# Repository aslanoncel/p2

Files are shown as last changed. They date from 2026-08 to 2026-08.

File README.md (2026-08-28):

# Marenova K1 — Vinç Makara Alt-Montajı (Parametrik CAD)

Yelkenli hidro-jeneratör masa prototipinin vinç makara alt-montajı için FDM 3D
baskıya uygun, tamamen parametrik CadQuery (Python) modeli.

## İçerik

```
cad/
  marenova_k1_winch.py   # tek parametrik kaynak dosya (tüm parçalar)
  stl/
    test_coupon.stl      # ~10 dk kalibrasyon kuponu — ÖNCE BUNU BASIN
    spool.stl            # makara
    motor_bracket.stl    # NEMA 17 motor braketi
    slipring_clamp.stl   # Ø12 kapsül slip ring tutucu
    line_guide.stl       # misina kılavuzu + limit switch bayrağı
```

## Kullanım

```bash
pip install cadquery
python3 cad/marenova_k1_winch.py
```

Betik `cad/stl/` altına her parça için ayrı STL yazar ve her parça için
hacim / tahmini kütle (PLA, %100 katı) / bounding box raporlar. Tüm kritik
ölçüler dosyanın başında parametre olarak tanımlıdır.

## Kalibrasyon iş akışı (önemli)

H7/g6 gibi işleme toleransları FDM'de geçersizdir; yerine baskı boşlukları
kullanılır:

| Parametre | Varsayılan | Anlam |
|---|---:|---|
| `CLEAR_SLIDE` | +0.20 mm | Mil geçmesi (makara ↔ NEMA17 D-şaft) |
| `CLEAR_PRESS` | +0.10 mm | Sıkı geçme (slip ring ↔ kelepçe) |
| `CLEAR_FREE`  | +0.35 mm | Serbest dönme (yedek) |

1. **Önce `test_coupon.stl` basın** (~10 dk): 5 mm D-şaft deliği + Ø12
   kelepçe deliği + Ø2 misina deliği içerir.
2. NEMA17 miline ve slip ring kapsülüne deneyin. Uymazsa `CLEAR_*`
   değerlerini 0.05 mm adımlarla değiştirip kuponu yeniden basın.
3. Boşluklar doğrulanınca asıl parçaları basın.

## Baskı yönelimleri (desteksiz)

| Parça | Yönelim |
|---|---|
| `spool` | Geldiği gibi: motor karşısı flanş tabana. Üst flanş 45° koni ile bağlanır, setskur göbeği en üstte, somun yuvası yukarı açık → köprü/destek yok. Kullanımda ters çevrilir (göbek motora bakar). |
| `motor_bracket`  | Geldiği gibi: taban tablaya. Ø23 delik gözyaşı tepeli, destekler 45°. |
| `slipring_clamp` | Yan yatık (geniş yüzeyi tablaya). Ø12 delik baskıda dikey → temiz daire. |
| `line_guide` | Yan yatık (geniş yüzeyi tablaya). |
| `test_coupon` | Geldiği gibi, düz. |

- Minimum et kalınlığı 2.4 mm (3 çeper × 0.8 mm nozul) gözetilmiştir.
- Somun cepleri baskı yönünde köprü gerektirmez (yukarı açık yuva veya
  kendini taşıyan çatılı cep).
- Makara hacmi ~219 cm³'tür; %15–20 infill ile basın (katı basmayın).

## Montaj notları

- Ortak eksen yüksekliği `AXIS_H = 45 mm` (MDF taban üstünden): motor mili,
  makara, slip ring ve kılavuz gözü aynı hizadadır.
- Makara: M3 başsız setskur (8 mm) göbekteki yukarıdan takılan M3 somuna
  vidalanır ve milin düz (D) yüzeyine basar.
- Slip ring: gövde kelepçeyle sabitlenir (dönmez); kapsülün kendi mili
  makarayla birlikte döner. Kelepçe M3×16 civata + somunla sıkılır.
- Kılavuz: esneme boynu sayesinde misina gerginliğiyle hafifçe salınır;
  salınım sonunda üstteki bayrak limit switch koluna basar.
- Tüm ayaklar 400×300 mm MDF tabana M4 vidayla bağlanır.

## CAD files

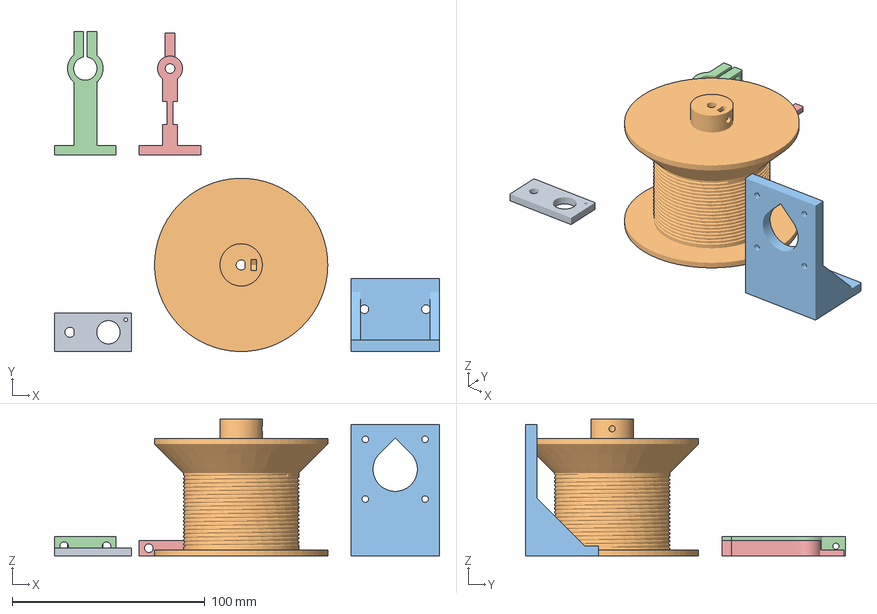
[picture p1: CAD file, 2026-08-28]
cad/marenova_k1_plate.3mf
199.9 x 166.2 x 71.0 mm
test_coupon
spool
motor_bracket
slipring_clamp
line_guide

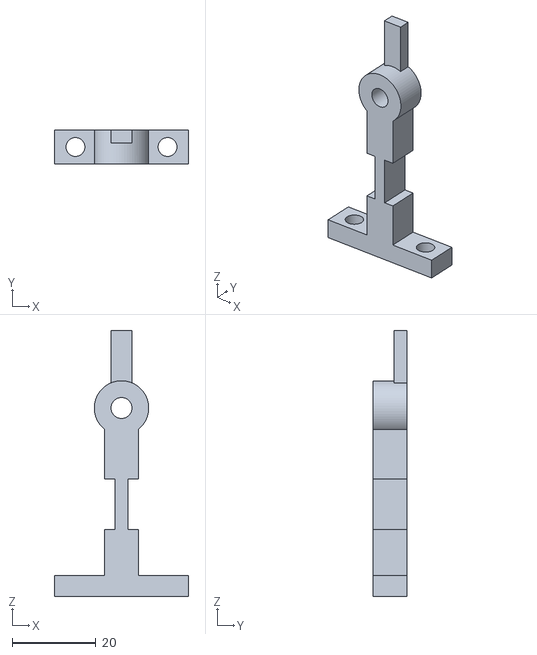
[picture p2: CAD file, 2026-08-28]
cad/stl/line_guide.stl
32.0 x 8.00 x 63.5

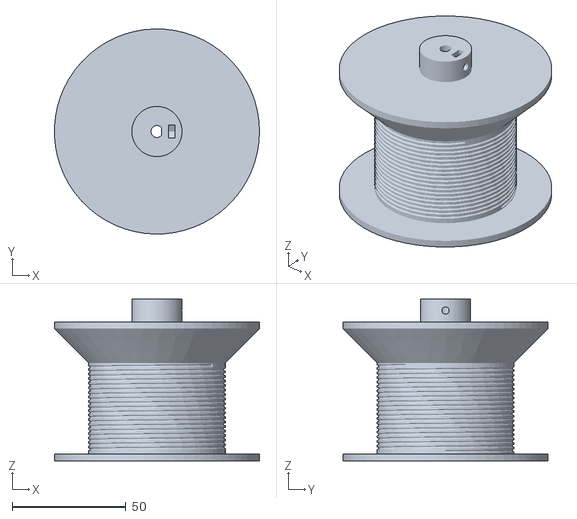
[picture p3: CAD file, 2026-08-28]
cad/stl/spool.stl
89.9 x 90.0 x 71.0

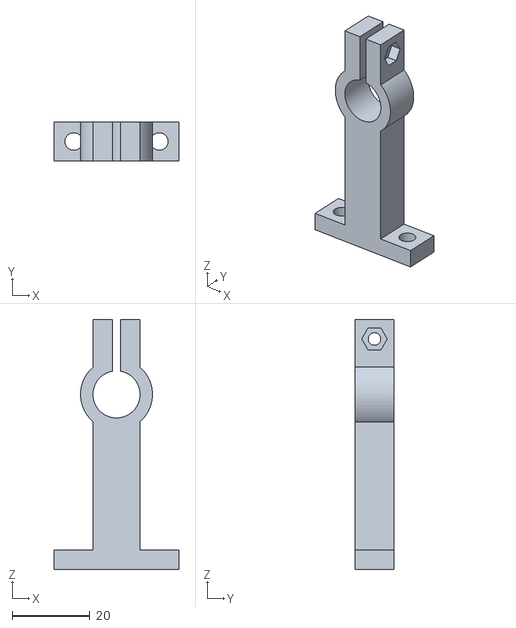
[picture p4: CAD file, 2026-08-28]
cad/stl/slipring_clamp.stl
32.0 x 10.0 x 64.2

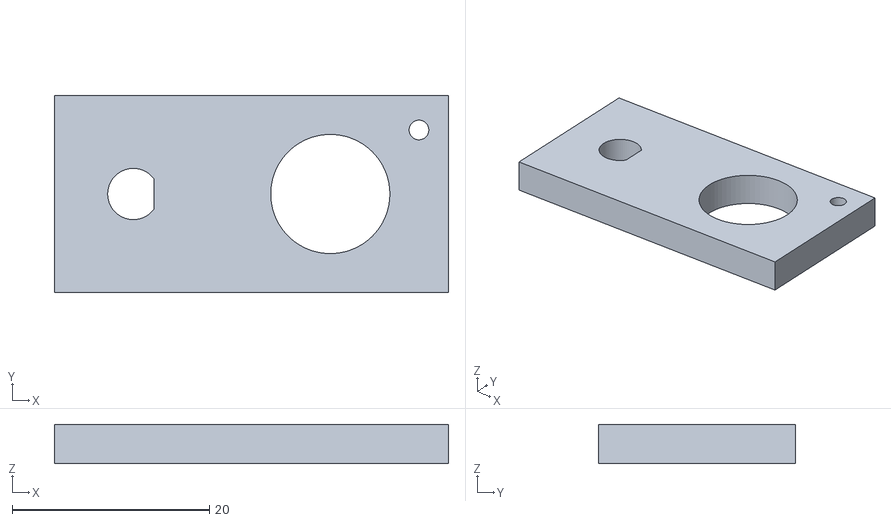
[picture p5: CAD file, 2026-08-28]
cad/stl/test_coupon.stl
40.0 x 20.0 x 4.00

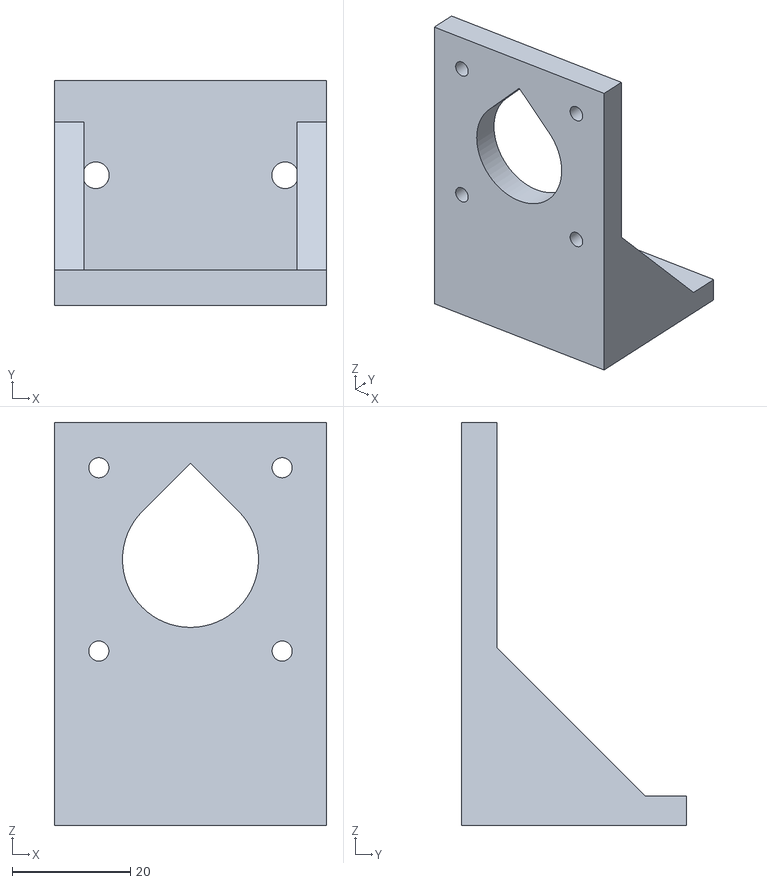
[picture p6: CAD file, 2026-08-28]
cad/stl/motor_bracket.stl
46.0 x 38.0 x 68.2

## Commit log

2026-08-28 Add parametric CAD for Marenova K1 winch pulley sub-assembly
    CadQuery source with all critical dimensions as top-level parameters:
    spool (D-shaft bore, set-screw hub, spiral groove), NEMA17 motor
    bracket, slip ring clamp, line guide with limit-switch flag, and a
    clearance calibration test coupon. Exports one STL per part and
    reports volume/mass/bounding box. All parts print support-free in
    the documented orientations.
    Claude-Session: https://claude.ai/code/session_01XDL1t2tydz3M7DRu9jvimP
    [line_guide.stl, motor_bracket.stl, slipring_clamp.stl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]
2026-08-28 Add ready-to-slice 3MF plate for Bambu Studio
    Generator script reads the exported STLs, rotates slipring_clamp and
    line_guide onto their print faces, arranges all five parts on a
    256x256 bed with gaps, and writes a multi-object 3MF that opens in
    Bambu Studio with named parts.
    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
    [marenova_k1_plate.3mf]
